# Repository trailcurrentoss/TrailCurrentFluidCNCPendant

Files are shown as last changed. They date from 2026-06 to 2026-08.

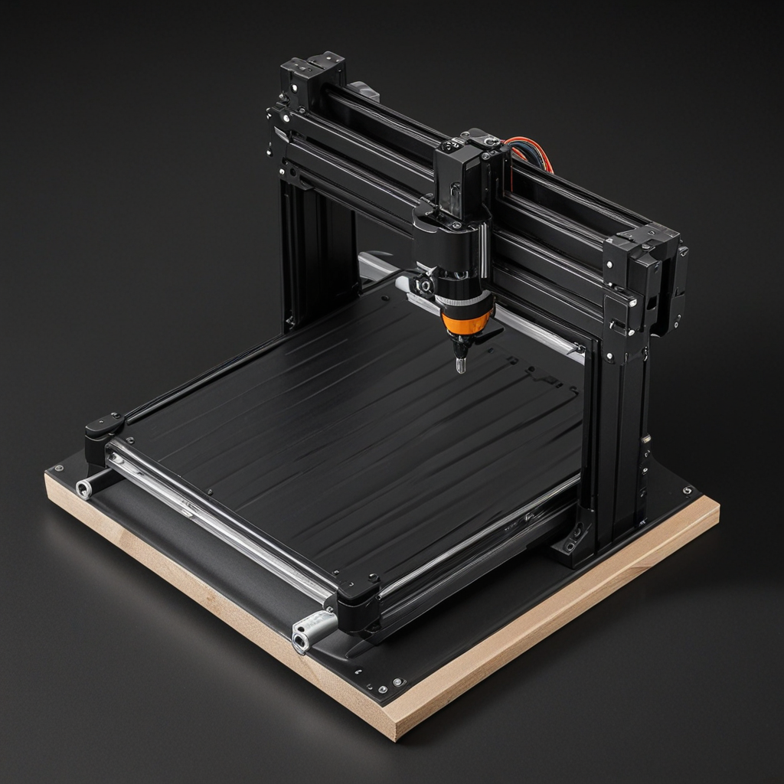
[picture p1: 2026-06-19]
assets/images/cnc_machine.png

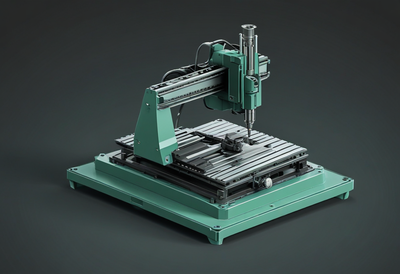
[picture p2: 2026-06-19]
assets/images/cnc_machine_ui.png

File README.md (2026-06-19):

# TrailCurrent FluidCNC Pendant

> # ⚠️ DEMONSTRATION CODE ONLY — DO NOT USE ON A REAL CNC MACHINE ⚠️
>
> **This project is published for educational and demonstration purposes only.**
> It is **not** a production CNC pendant. It has **not** been validated for
> safety, reliability, or fitness for any purpose. **DO NOT** use it to control
> a real CNC machine — milling, lathe, laser, plasma, router, or otherwise.
>
> CNC machines are dangerous. They can injure you, others, or damage equipment
> and material if commands are sent incorrectly, are ignored, or arrive out of
> order. This pendant offers **no safety guarantees**: commands can be dropped,
> rejected, delayed, or executed in unexpected sequences. The on-screen
> "E-STOP" button is **not** a substitute for a hardware emergency stop.
>
> If you build, flash, or modify this code, you do so **entirely at your own
> risk**. The authors and contributors accept **no liability** for any damage,
> injury, loss, or other consequences arising from its use or misuse.
>
> For real CNC control, use FluidNC's official tools and a properly engineered
> physical e-stop circuit wired directly to your controller.

---

A touch-screen control panel for [FluidNC](https://github.com/bdring/FluidNC)
CNC controllers. Mount it on the side of your CNC machine and use it to
home the spindle, jog the axes, start a job, set work coordinates, run macros,
and watch what the machine is doing — all without reaching for a laptop.

**Hardware:** [Waveshare ESP32-P4 WiFi6 Touch LCD 7B](https://www.waveshare.com/wiki/ESP32-P4-WIFI6-Touch-LCD-7B) — 7-inch 1024×600 capacitive touch panel with an ESP32-P4 main chip and an ESP32-C6 WiFi co-processor.
**Firmware:** ESP-IDF 5.5.x · LVGL 8.4 · UI authored in [EEZ Studio](https://www.envox.eu/studio/).

---

## Quick start

1. Flash the firmware — see [docs/06-building-and-flashing.md](docs/06-building-and-flashing.md).
2. On first boot the pendant scans for WiFi networks — pick yours, enter the password.
3. Open Settings → Machine → "Configure FluidNC Connection" — type your
   controller's hostname or IP, pick **WebSocket** for wireless or **UART** for wired.
4. Tap **Connect** and the pendant lands on the Dashboard with live machine readouts.

## Documentation

Full documentation lives in [docs/](docs/). Start with [docs/README.md](docs/README.md) for a guided tour.

| If you want to… | Read |
|---|---|
| Understand what the pendant does and who it's for | [01-overview.md](docs/01-overview.md) |
| Get the pendant onto WiFi and talking to your CNC | [02-getting-started.md](docs/02-getting-started.md) |
| Know what every screen does | [03-screen-tour.md](docs/03-screen-tour.md) |
| Understand how it talks to FluidNC under the hood | [04-how-it-talks-to-fluidnc.md](docs/04-how-it-talks-to-fluidnc.md) |
| Read the code — what lives where | [05-architecture.md](docs/05-architecture.md) |
| Build and flash the firmware | [06-building-and-flashing.md](docs/06-building-and-flashing.md) |
| Change colors, add screens, or modify behavior | [07-customizing.md](docs/07-customizing.md) |
| Fix something that's not working | [08-troubleshooting.md](docs/08-troubleshooting.md) |

## Project layout

| Path | Purpose |
|---|---|
| [main/](main/) | Application code — state machine, action handlers, variable bridge |
| [main/ui/](main/ui/) | UI generated by EEZ Studio — **never edit by hand** |
| [GUI/](GUI/) | EEZ Studio project file (`.eez-project`) — source of truth for the UI |
| [components/fluidnc/](components/fluidnc/) | FluidNC protocol — WebSocket / UART transports, grbl parser, dispatcher |
| [components/wifi_setup/](components/wifi_setup/) | WiFi scan + connect via the ESP32-C6 co-processor |
| [components/pendant_config/](components/pendant_config/) | Persistent settings stored in NVS (flash) |
| [assets/](assets/) | Source images, fonts, icons referenced by the EEZ Studio project |
| `sdkconfig.defaults` | Pinned project config — edit here, never `sdkconfig` |

## Status

- ✅ All UI screens render and respond to touch
- ✅ Real FluidNC protocol backend (WebSocket + UART), grbl status parser
- ✅ WiFi setup and auto-reconnect via ESP-Hosted to the ESP32-C6
- ✅ Persistent settings (WiFi creds, host, port, units, brightness, theme)
- ✅ Mock backend selectable via `idf.py menuconfig` for bench testing
- 🟡 Probe cycles 1–3 (corner / center / tool length) — only Z touch-off implemented
- 🟡 Pagination for SD listings > 6 files

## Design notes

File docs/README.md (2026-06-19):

# TrailCurrent FluidCNC Pendant — Documentation

Welcome. This folder is the full documentation for the pendant — written so
someone who's never touched the project (and doesn't have a CNC background)
can read it cover to cover and end up knowing what the device does, how to
use it, and how it's built.

## Reading order

If you're new, read in order. If you already know what a CNC is and just
want to set the pendant up, skip to [02 — Getting started](02-getting-started.md).
If you're a developer who wants to modify the code, [05 — Architecture](05-architecture.md)
is the starting point.

| # | Topic | What's in it |
|--:|---|---|
| 01 | [Overview](01-overview.md) | What the pendant is, who it's for, the hardware |
| 02 | [Getting started](02-getting-started.md) | First boot — WiFi setup, connecting to a CNC |
| 03 | [Screen tour](03-screen-tour.md) | Every screen, every button, what it does |
| 04 | [How it talks to FluidNC](04-how-it-talks-to-fluidnc.md) | The protocol in plain English |
| 05 | [Architecture](05-architecture.md) | Code organisation — where things live and why |
| 06 | [Building and flashing](06-building-and-flashing.md) | Compiling and getting firmware on the device |
| 07 | [Customizing](07-customizing.md) | Changing screens, themes, actions |
| 08 | [Troubleshooting](08-troubleshooting.md) | Common problems and how to fix them |

## Glossary

Terms used throughout the docs. Skim once, refer back as needed.

- **CNC** — Computer Numerical Control. A milling machine, lathe, plasma cutter,
  laser, etc. that moves automatically under software control.
- **FluidNC** — open-source CNC controller firmware that runs on an ESP32 board
  connected to the stepper drivers. The pendant talks to it as a remote.
- **g-code** — the text language CNC machines speak. Commands look like
  `G1 X100 Y50 F1500` (move to X=100, Y=50 at 1500 mm/min). The pendant sends
  these to FluidNC behind the scenes when you tap a button.
- **grbl** — an older CNC firmware FluidNC inherits its wire protocol from. The
  status reports and realtime control bytes the pendant uses come from grbl.
- **Jog** — small, manually-commanded movement (used to position the spindle
  before running a job).
- **Home** — automatic move to the machine's reference position, used so the
  controller knows where the spindle physically is.
- **WCS** — Work Coordinate System. Lets you set "this corner of my material
  is zero" without moving the machine. FluidNC supports 6: `G54`–`G59`.
- **DRO** — Digital ReadOut. The big numbers on the screen showing where the
  spindle currently is.
- **LVGL** — the C library that draws everything on the screen.
- **EEZ Studio** — the visual designer used to lay out the pendant's screens.
  Saves to a `.eez-project` JSON file, which the build process turns into C code.
- **ESP-IDF** — Espressif's development framework for the ESP32 family of chips.
  Provides the compiler, flashing tool, and system libraries.
- **NVS** — Non-Volatile Storage. A small flash partition where the pendant
  remembers your WiFi password, controller address, and preferences.

If a term shows up in the docs that isn't here, let us know — we'll add it.

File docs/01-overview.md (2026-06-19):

# 01 — Overview

## What is the pendant?

It's a 7-inch touchscreen that sits next to your CNC machine and acts as
the everyday control surface for it. You touch the screen to jog the
spindle, start a job, set zero positions, adjust feed and spindle speed,
and watch what the machine is doing.

Today most people running [FluidNC](https://github.com/bdring/FluidNC) (the
controller firmware this pendant talks to) reach the controller through a
web browser on a laptop or phone — point it at the controller's IP address
and you get the FluidNC web UI. That works, but it means a laptop on the
shop bench, an open browser tab, and your attention split between the
screen and the machine.

The pendant replaces that web UI with a purpose-built, always-on,
single-purpose touch panel. It mounts on the side of the machine. You walk
up, tap, and it does the thing.

```
┌─────────────────────────────────────────────────────────┐
│  ●  TrailCurrent              ●  IDLE   G54   --:--     │  ← Status bar
├─────────────────────────────────────────────────────────┤
│  ALARM RIBBON (hidden unless the machine alarms)        │
├─────────────────────────────────────────────────────────┤
│                                                         │
│            Whatever the active screen is                │
│            (Dashboard, Jog, Files, …)                   │
│                                                         │
├─────────────────────────────────────────────────────────┤
│  ▥ Dash · ✥ Jog · ▶ Run · 🗎 Files · 𝍝 Spindle · …      │  ← Bottom dock
└─────────────────────────────────────────────────────────┘
```

## Who is it for?

- **Hobbyists** running a small CNC mill, router, plasma cutter, or laser
  with a FluidNC controller, who want a tidy permanent control surface
  instead of a laptop on the bench.
- **Small shops** that want a consistent, fast UI for operators who
  shouldn't need to learn the browser-based FluidNC web UI.
- **Makers building their own CNC** who already have FluidNC on the
  controller side and want a matching front panel.

You **do not** need this pendant if FluidNC's built-in web UI on your phone
or laptop is meeting your needs — this is a hardware-and-software project
that involves buying a specific touchscreen and flashing firmware to it.

## What runs on it?

| Component | What it is |
|---|---|
| **Hardware** | Waveshare ESP32-P4 WiFi6 Touch LCD 7B board — a 7-inch 1024×600 capacitive touch panel with an ESP32-P4 main chip (no WiFi of its own) and a small ESP32-C6 co-processor that handles WiFi. |
| **Firmware framework** | [ESP-IDF 5.5](https://docs.espressif.com/projects/esp-idf/) — Espressif's official development framework. Provides the compiler, FreeRTOS, drivers, and flash tools. |
| **Graphics library** | [LVGL 8.4](https://lvgl.io/) — a lightweight C library that draws all the widgets (buttons, sliders, labels) and handles touch input. |
| **UI design tool** | [EEZ Studio](https://www.envox.eu/studio/) — a free visual editor for LVGL screens. The pendant's layout is designed in EEZ Studio and saved as a JSON file under [GUI/](../GUI/). |
| **CNC protocol** | The pendant speaks the same wire protocol FluidNC inherited from [grbl](https://github.com/grbl/grbl) — short g-code lines (`G0 X10`) and single "realtime" control bytes (`?` for status, `!` for hold, etc.). |

## What does it *not* do?

- It does **not** generate g-code. You create g-code somewhere else (CAM
  software like Fusion 360, Carbide Create, Kiri:Moto, etc.) and put the
  files onto FluidNC's SD card or local filesystem. The pendant browses
  and runs those files; it doesn't author them.
- It does **not** control stepper motors or relays directly. The CNC
  controller (an ESP32 board running FluidNC firmware) does all the
  motion. The pendant just talks to it.
- It does **not** include an emergency stop hardware button. The
  on-screen E-STOP sends a soft-reset command to FluidNC, which stops
  motion — but for real safety you should still have a physical
  emergency stop wired directly to the controller's input.
- It does **not** record video, host a camera, or stream the workshop
  anywhere. It's a control panel, not a monitor.

## How is it organised?

The pendant has **10 screens**, grouped in two phases:

**Setup screens** (shown only when there's something to set up):

- **WifiSetup** — scan and join a WiFi network
- **FluidConnect** — tell the pendant your controller's address and connect

**Operating screens** (the eight tabs in the bottom dock):

- **Dashboard** — the home screen; big position display, job progress, override sliders
- **Jog** — manually move each axis, zero coordinates, switch units
- **Run** — start/stop the current job, see g-code preview, monitor progress
- **Files** — browse the controller's SD card, pick a file to load
- **Spindle** — RPM dial, target speed, coolant on/off
- **Probe** — touch-off cycles for finding work zero or tool length
- **Macros** — eight one-tap shortcuts for things like "park", "tool change", "warm up spindle"
- **Settings** — preferences (units, brightness, theme), system info, WiFi management

[Chapter 03 — Screen tour](03-screen-tour.md) walks through each screen in detail.

## Where to next?

- If you have the hardware and want to use it: **[02 — Getting started](02-getting-started.md)**.
- If you just want to know what each screen does: **[03 — Screen tour](03-screen-tour.md)**.
- If you're a developer wanting to read the code: **[05 — Architecture](05-architecture.md)**.

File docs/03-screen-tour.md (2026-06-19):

# 03 — Screen tour

This chapter walks through every screen and every button. If you're trying
to figure out "what does this do?" while looking at the pendant, this is
the chapter to keep open.

## Things common to every screen

### Top status bar

Always visible at the top of every operating screen.

```
●  TrailCurrent  ●  IDLE   G54   13:42   📶   ‖ HOLD  ⏹ E-STOP   X 12.345  Y 67.890  Z  -1.230
```

- **● TrailCurrent** — brand mark on the left.
- **● Status pill** — a coloured chip showing the controller's state:
  - **IDLE** (neutral) — the controller is on but not moving.
  - **RUN** (green) — running a job or jogging.
  - **JOG** (green) — actively jogging in response to your taps.
  - **HOLD** (orange) — feed hold is engaged (paused mid-motion).
  - **HOMING** (orange) — running a homing cycle.
  - **ALARM** (red) — something tripped; the controller will refuse to move
    until you reset the alarm.
  - **OFFLINE** (red) — the pendant can't reach the controller.
- **G54** — the active work coordinate system.
- **13:42** — the on-board clock (not yet wired to network time; static for now).
- **📶 WiFi icon** — shown when the pendant is connected to WiFi.
- **‖ HOLD button** — same as the realtime feed hold: tap to pause motion.
  When already held, the label changes to **▶ RESUME**.
- **⏹ E-STOP button** — soft reset; stops motion and puts the controller in
  alarm state. For real emergencies you should still have a hardware
  e-stop wired to the controller.
- **X / Y / Z mini-DRO** — current position, condensed. Same as the big
  DRO on Dashboard / Jog but always visible no matter what screen you're on.

### Alarm ribbon

Appears as a red band below the status bar **only when the machine is in
alarm**. Shows the alarm code and a description; tap **RESET** on the
right side to clear it (sends `$X` to FluidNC).

### Bottom dock

Always visible at the bottom. Eight icon-and-label buttons that switch
between operating screens. The active one is highlighted.

```
▥ Dash   ✥ Jog   ▶ Run   🗎 Files   𝍝 Spindle   ✚ Probe   ⚡ Macros   ⚙ Settings
```

---

## Dashboard (▥ Dash)

The home screen. Everything you need to see at a glance during a job.

```
┌──────────────── Top status bar ────────────────┐
├────────────────────────────────────────────────┤
│  POSITION                          mm          │
│  X  [+12.345]   ▣Zero                          │
│  Y  [+67.890]   ▣Zero                          │
│  Z  [ -1.230]   ▣Zero                          │
├────────────────────────────────────────────────┤
│  FEED 100%   ─◖████████◗────  − +              │
│  RAPID 100%  ─◖████████◗────  − +              │
│  SPINDLE 100%─◖████████◗────  − +              │
├────────────────────────────────────────────────┤
│  JOB · bracket_v3.nc · 23%                     │
│  ████████░░░░░░░░░░░░░░░ Line 142 / 612        │
│  Elapsed 02:45    ETA 09:12                    │
├────────────────────────────────────────────────┤
│  𝍝 Spindle 12000 rpm   ⛆ Flood   ☷ Mist   ⌂ Home│
└─────────────────── Bottom dock ────────────────┘
```

- **POSITION card** — work-coordinate position, big. Tapping the **Zero**
  button next to an axis zeros that axis in the active WCS (sends
  `G10 L20 P0 X0`). The unit (mm or in) sits at the top right and reflects
  whatever you've picked in Settings.
- **Override card (Feed / Rapid / Spindle)** — three rows showing each
  override percentage. Tap **−** to drop by 10, **+** to bump by 10, and
  tap the percentage value itself to reset to 100. The bars fill to
  visualise the current value. *Note:* Rapid only has three legal grbl
  values (25 %, 50 %, 100 %) so taps cycle between those.
- **JOB card** — only meaningful during a run. Shows file name, percent,
  current line / total lines, elapsed time, ETA. When no job is running
  it shows placeholders.
- **Tile row** — four quick-access tiles:
  - **𝍝 Spindle** — tap to start/stop the spindle at the current target RPM.
  - **⛆ Flood** — toggle coolant flood (`M8` / `M9`).
  - **☷ Mist** — toggle coolant mist (`M7` / `M9`).
  - **⌂ Home** — run `$H` (homing cycle). The pendant will refuse if the
    controller is in alarm or already running.

## Jog (✥ Jog)

For manually moving the spindle around. Two DROs (work + machine
coordinates), a WCS picker, units, step-size buttons, and the directional pad.

- **Work / Machine DRO** — two columns, X/Y/Z each. Work is in the active
  WCS; machine is from the homed reference. Both update live.
- **WCS chips (G54–G59)** — tap any to switch active WCS (sends the
  matching g-code). The currently active one stays highlighted.
- **Units chips (mm / in)** — switch the controller's units (`G21` / `G20`)
  and the on-screen formatting. Saved to flash so it survives reboot.
- **Step size buttons (0.01 / 0.1 / 1.0 / 10)** — picks how far each tap
  of a direction button moves the spindle. Distance is in the current units.
- **Directional pad** — X+/−, Y+/−, Z+/−, with a Home button in the centre.
  Each tap fires a `$J=…` jog command at the current step size and the
  feed rate from Settings → Motion → Default Jog Feed.
- **Zero row (X 0 · Y 0 · Z 0 · All 0)** — instant zero buttons for each
  axis or all three at once.

## Run (▶ Run)

The job runner. Open this screen when you're about to start cutting.

- **Header card** — current file name, percent complete, progress bar,
  elapsed time, time remaining, current line.
- **G-code preview** — scrolling window of 20 lines of the program around
  the line currently executing. Line numbers on the left, g-code text on
  the right. (Static placeholder text today; live preview to come.)
- **Status card** — quick read of spindle RPM, feed rate, coolant state.
- **Start / Hold / Stop buttons**:
  - **▶ Start** — begins running the file currently loaded
    (`$LocalFS/Run=/spiffs/<name>` to FluidNC).
  - **‖ Hold** — feed hold (`!` realtime byte).
  - **⏹ Stop** — soft-reset then `$X` — stops motion and clears the alarm
    state so you can immediately run again or jog.

## Files (🗎 Files)

Browser for the g-code files stored on the FluidNC controller's local
filesystem (or SD card, depending on your FluidNC config).

- **Left side — file list** — up to 6 rows showing file name, size, date.
  Tap a row to select it (highlights green). The file count is shown above.
- **Refresh button** — re-queries the controller's file listing
  (`$LocalFS/List`). Useful after you've uploaded a new file via FluidNC's
  web UI.
- **Right side — Selected card** — shows the currently selected file's
  name and metadata (size, line count, runtime estimate).
- **Load & Run button** — equivalent to tapping the file then going to Run
  and tapping Start; one-tap shortcut.
- **Staging card** — placeholder for upload progress when streaming files
  from the pendant (not yet implemented; SD-on-controller is the current path).

> The pendant doesn't store g-code files itself — it always reads them
> from the controller. To get a new file onto the controller, use FluidNC's
> web UI (browse to its IP address in any browser) and upload there, then
> tap Refresh on the pendant.

## Spindle (𝍝 Spindle)

Dedicated spindle control screen, more detailed than the Dashboard tile.

- **Left card — RPM dial** — a big arc showing current RPM vs the target.
  Below it a Start/Stop button (label changes based on state).
- **Target card** — current target RPM with **−** / **+** buttons that
  step by 500 RPM. The displayed target is the value sent to FluidNC the
  next time the spindle is started (or, if already spinning, sent
  immediately as a new `M3 S…` line).
- **Load card** — spindle load (% of max). FluidNC reports this if the
  spindle driver supports load reporting; otherwise it stays at 0.
- **Coolant card** — Flood and Mist toggles. Same actions as the
  Dashboard tile row.

## Probe (✚ Probe)

Touch-off cycles for finding the surface of your material (so the
controller knows where Z=0 is) and similar reference operations.

- **Probe cycle picker (left)** — four cycle types:
  - **Z touch-off** — basic Z probe down + back off + set Z. *Implemented.*
  - **Corner** — find an outside corner of the stock. *Not yet implemented.*
  - **Center** — find the centre of a circular pocket / boss. *Not yet implemented.*
  - **Tool length** — measure tool length offset. *Not yet implemented.*
- **Parameters (right)** — three values:
  - **Plate thickness** — thickness of your probing plate in mm.
  - **Feed** — probe approach speed in mm/min.
  - **Travel** — maximum distance the probe will try before giving up.
- **Probe Z indicator** — last measured Z value. Shows "—" before a probe runs.
- **Start Probe button** — sends the probe sequence based on the selected cycle.

## Macros (⚡ Macros)

Eight tiles, each running a preset multi-line g-code snippet. Defaults
shipped:

| Tile | Macro |
|---|---|
| Go To Front | `G53 G90 G0 Z0` then `G53 G0 X0 Y0` |
| Tool Change | `M6` |
| Probe Z | `G38.2 Z-25 F100` |
| Spindle Warm | `M3 S8000` · `G4 P60` · `M5` |
| Set G54 Zero | `G10 L20 P1 X0 Y0 Z0` |
| Spindle Warmup | (duplicate of Spindle Warm) |
| Park Rear Right | `G53 G0 X-10 Y-10` |
| Unlock | `$X` |

To change what a macro does, edit the `k_macros[]` array in
[main/actions.c](../main/actions.c) and rebuild.

## Settings (⚙ Settings)

Tabbed settings page with five sub-tabs along the left.

### Settings → Machine

- **Units** — mm / inch. Sends `G21` / `G20` to the controller and saves
  the preference to flash.
- **Home on boot** — switch. If on, the pendant tells the controller to
  home immediately on connect. *Stored as a preference; behaviour wiring
  is a follow-up.*
- **Configure FluidNC Connection** — opens the FluidConnect screen so you
  can change the controller host / port / transport without re-doing WiFi.

### Settings → Connection

- **SSID** — the WiFi network the pendant is currently connected to.
- **State** — `Connected · 192.168.x.y` / `Disconnected` / `Failed`.
- **Change Network** — kicks the pendant back to the WiFi setup screen
  so you can pick a different network.
- **Forget** — drops the saved credentials and disconnects. Next boot
  will show the WiFi setup screen.

### Settings → Motion

- **Soft limits** — switch (preference only; FluidNC's `$20=1` is set in
  its own YAML).
- **Hard limits** — switch (preference only).
- **Default jog feed** — slider, 60–6000 mm/min. The Jog page uses this
  whenever you tap a directional button.

### Settings → System

Read-only info:

- **Firmware** — what FluidNC version the controller reported (parsed
  from the `[VER:…]` line FluidNC sends on `$I`).
- **Controller** — the chip identifier the controller reported.
- **UI** — `LVGL 8.4 · 1024x600`.
- **Network** — same string as the Connection tab's State field.

### Settings → Display

- **Brightness** — slider 0–255 with live preview. Saved to flash.
- **Screen timeout** — minutes until the screen blanks for inactivity
  (0 = never). Tapping the dark screen wakes it.
- **Theme** — Light / Dark. The Dark theme is the production look;
  Light is currently a near-mirror (placeholder for a real light palette).

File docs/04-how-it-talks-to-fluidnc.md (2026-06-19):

# 04 — How it talks to FluidNC

This chapter explains the conversation between the pendant and the
FluidNC controller. You don't need to read it to use the pendant — it's
here for the curious, and for anyone debugging a connection that's not
behaving.

## The big picture

The FluidNC controller speaks an old, simple, text-based protocol it
inherited from a project called grbl. Lines of text go in either
direction over the link (WiFi or wired serial). The pendant is just a
client that:

1. **Polls** the controller four times a second for its current state
   ("where's the spindle? what's running? any alarms?"), and
2. **Sends commands** when you tap buttons ("move +1 mm in X", "start
   spinning at 12000 rpm", "stop everything").

```
   ┌─────────────────┐                   ┌─────────────────┐
   │  PENDANT        │                   │  FluidNC        │
   │  (ESP32-P4)     │ ── "?" ─────────▶ │  controller     │
   │                 │                   │  (ESP32 board   │
   │                 │ ◀── "<Idle|...>" ─│  + stepper      │
   │                 │                   │   drivers)      │
   │                 │ ── "G0 X10" ────▶ │                 │
   │                 │ ◀── "ok" ─────────│                 │
   └─────────────────┘                   └─────────────────┘
```

## What goes over the wire

### Status reports (the most common message)

Four times a second the pendant sends a single byte: `?` (question mark).
FluidNC responds with one line in angle brackets, packed with comma-
separated key-value fields:

```
<Run|MPos:12.345,67.890,-1.230|FS:1500,12000|Ov:100,100,100|Pn:|A:SF>
```

Decoded:

- `Run` — current state (Idle / Run / Hold / Jog / Home / Alarm / Door / Check / Sleep)
- `MPos:12.345,67.890,-1.230` — machine position (X, Y, Z), in mm by default
- `FS:1500,12000` — current feed rate (mm/min) and spindle speed (rpm)
- `Ov:100,100,100` — feed / rapid / spindle override percentages
- `Pn:` — triggered pin flags (probe, limits) — empty here means none
- `A:SF` — accessory state: `S` = spindle clockwise, `F` = flood on

The pendant parses this in [src/proto.c](../components/fluidnc/src/proto.c)
and updates every widget that displays one of these values — DRO numbers,
status pill text and colour, override bars, spindle dial, coolant tile
states.

### Realtime control bytes (single byte, no newline)

Some controls bypass the line-by-line command queue because they need to
take effect immediately:

| Byte | Hex  | Meaning |
|---|---|---|
| `?` | `0x3F` | Status report request |
| `!` | `0x21` | Feed hold (pause motion mid-move) |
| `~` | `0x7E` | Cycle start / resume |
| `\x18` | `0x18` | Soft reset (used as E-STOP) |
| `\x85` | `0x85` | Jog cancel |
| `\x90`–`\x9D` | | Feed / rapid / spindle override step commands |
| `\xA0` | `0xA0` | Toggle flood coolant |
| `\xA1` | `0xA1` | Toggle mist coolant |

The pendant uses these for the E-STOP button, the HOLD / RESUME button,
and the override − / + buttons. They go out instantly without queueing.

### G-code lines (everything else)

Anything that takes a `\n` to terminate is g-code. The pendant
constructs and sends:

| Pendant action | What the pendant sends |
|---|---|
| Tap Jog X+ at 1 mm, 1200 mm/min | `$J=G91 G21 X1.0000 F1200.0\n` |
| Zero X in current WCS | `G10 L20 P0 X0\n` |
| Switch to G55 | `G55\n` |
| Switch to inch | `G20\n` |
| Home all | `$H\n` |
| Start spindle at 12000 | `M3 S12000\n` |
| Stop spindle | `M5\n` |
| Flood on / off | `M8\n` / `M9\n` |
| Reset alarm | `$X\n` |
| Start a job | `$LocalFS/Run=/spiffs/bracket_v3.nc\n` |
| Get file listing | `$LocalFS/List\n` |
| Z probe | `G38.2 Z-25 F100\n` then `G10 L20 P0 Z19.00\n` then `G0 Z24.00\n` |

The controller responds to each line with `ok` (accepted) or `error:N`
(rejected, where N is the grbl error code). The pendant doesn't surface
every error today — that's a future enhancement.

## Transports

The pendant supports three ways to physically reach the controller. You
pick one on the FluidConnect screen.

### WebSocket (wireless — recommended)

FluidNC exposes the grbl protocol over a WebSocket on
`ws://<controller-ip>:81/` (FluidNC 3.x) or `ws://<controller-ip>:80/`
(FluidNC 4.x). The pendant connects via the
[`esp_websocket_client`](https://components.espressif.com/components/espressif/esp_websocket_client)
library and treats each WebSocket text frame as one or more newline-
separated grbl lines.

Source: [src/transport_ws.c](../components/fluidnc/src/transport_ws.c).

### UART (wired)

If WiFi isn't reliable in your shop, or you just prefer wires, the
pendant can talk grbl over a UART pair instead. Wiring:

- Pendant GPIO 5 (TX) → Controller RX
- Pendant GPIO 4 (RX) → Controller TX
- Pendant GND → Controller GND
- 115200 8N1, no flow control

Match this baud rate in your FluidNC YAML config (usually under
`uart1:` or similar). Source:
[src/transport_uart.c](../components/fluidnc/src/transport_uart.c).

### Telnet (stub)

The pendant config knows about Telnet because FluidNC exposes one, but
the transport isn't implemented yet. Picking it returns a "not supported"
error. WebSocket is functionally equivalent for almost every use case.

## Inside the pendant — the dispatcher

When the pendant talks to FluidNC, three things happen on three different
FreeRTOS tasks:

1. **Status-poll task** — sends a `?` byte every 250 ms when the link is up.
2. **RX-parse task** — reads incoming bytes one chunk at a time, splits
   them at newlines, classifies each line (`<Status>`, `ok`, `error:N`,
   `[FILE:…]`, etc.), and updates the cached status struct.
3. **The widget refresh** — after every parsed status report, a callback
   fires that pushes the new values into the UI variables, which in
   turn update every relevant LVGL widget across all 8 screens.

The dispatcher (the brains tying these together) is in
[src/fluidnc.c](../components/fluidnc/src/fluidnc.c). The public API
(`fluidnc_jog`, `fluidnc_spindle_on`, etc.) is in
[include/fluidnc.h](../components/fluidnc/include/fluidnc.h).

## When things go wrong

### Connection drops mid-use

If the WebSocket disconnects, the pendant detects it and tries to
reconnect automatically. The status pill flips to **OFFLINE** while
disconnected and back to **IDLE** (or whatever state) when the link
recovers. UART links don't auto-detect drop the same way; you have to
pull power and reconnect.

### Controller alarms

When FluidNC enters alarm state, its next status report includes an
`Alarm` state token and the pendant:

1. Flips the status pill to red.
2. Shows the red **Alarm ribbon** across the top of every screen.
3. Refuses to send motion commands (e.g. jog) until alarm is cleared.

Tap **Reset** on the alarm ribbon (or the alarm-state pill) to send
`$X` and clear it.

### Commands that don't take effect

If you tap a button and nothing happens, possibilities are:

- The controller is in alarm (motion blocked until cleared).
- The controller is running a job (some commands queue, some are ignored).
- The link is down (status pill shows OFFLINE).
- The command was sent but FluidNC rejected it with `error:N` — these
  are logged on the pendant's serial console (USB-C) but not currently
  shown on screen.

For more on debugging, see [08 — Troubleshooting](08-troubleshooting.md).

## Mock backend (for bench testing without a real controller)

If you want to develop or demo the pendant without hooking it up to a
real CNC, the project ships a mock backend that simulates motion,
spindle ramp, file listings, and job progress. Enable it via:

```bash
idf.py menuconfig
# → TrailCurrent FluidNC → Use mock backend → Y
idf.py build flash
```

The mock lives in
[src/fluidnc_mock.c](../components/fluidnc/src/fluidnc_mock.c). It's
useful when:

- You want to test UI changes without standing next to a CNC.
- You want to record demo video of the pendant.
- The real controller isn't built/wired yet.

To go back to the real backend, set the option to N and rebuild.

## Useful FluidNC documentation

- [FluidNC wiki](https://github.com/bdring/FluidNC/wiki) — official docs
- [grbl realtime commands](https://github.com/gnea/grbl/wiki/Grbl-v1.1-Commands#real-time-commands) — full byte list
- [grbl status report format](https://github.com/gnea/grbl/blob/master/doc/markdown/interface.md#status-reporting) — field reference

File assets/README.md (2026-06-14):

# Assets

Source artwork that feeds the EEZ Studio project in [../GUI/](../GUI/). EEZ Studio imports from here; **nothing in this folder is consumed at firmware build time** — it is design-time material only.

## Layout

```
assets/
├── fonts/
│   └── fontawesome/         # OTF (Solid, Regular, Brands) — for LVGL font subsetting
├── icons/
│   └── fontawesome/         # Font Awesome 7.2.0 Free icon raster + vector sets
│       ├── svg/{solid,regular,brands}/        # 2860 vector source SVGs
│       ├── png16/{solid,regular,brands}/      # 2860 PNGs rasterized at 16x16 px
│       ├── png32/{solid,regular,brands}/      # 2860 PNGs rasterized at 32x32 px
│       └── LICENSE.txt
├── images/                  # Project bitmap art (screen backgrounds, logos, etc.)
└── source/                  # Editable masters (SVG, AI, PSD, FreeCAD exports, …)
```

## Font Awesome

- Version: **7.2.0 Free** (CC BY 4.0 for icons, SIL OFL 1.1 for fonts, MIT for code — see `LICENSE.txt`).
- Family counts: solid (2000), regular (273), brands (587). Total: **2860 icons**.
- PNGs are black-on-transparent ARGB, centered, uniformly scaled to fit the canvas.
- Use the **SVG** when EEZ Studio is the consumer (vector → any size, recolorable).
- Use the **PNG** when you need a guaranteed pixel-aligned raster at the chosen size.
- Use the **OTF** when subsetting an LVGL icon font (typical for buttons that mix icon+text).

## Adding new assets

1. Drop the master file into `assets/source/`.
2. Export the production-format file (PNG / SVG) into `assets/images/` or `assets/icons/`.
3. Import into EEZ Studio from there.

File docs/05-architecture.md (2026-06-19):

# 05 — Architecture

A developer-oriented map of the codebase: what files exist, what
responsibilities each one has, and how they wire up.

If you've never read an ESP-IDF project before, the [README's project
layout table](../README.md#project-layout) and this chapter together
should be enough to find your way around.

## The 30-second summary

```
                       ┌──────────────────────────────────┐
                       │  EEZ Studio (.eez-project JSON)  │
                       │  ─ designed in the GUI app       │
                       │  ─ defines every screen, style,  │
                       │    action declaration, font      │
                       └──────────────┬───────────────────┘
                                      │  Build (Ctrl+B in EEZ Studio)
                                      ▼
                       ┌──────────────────────────────────┐
                       │  main/ui/*.c|*.h  (GENERATED)    │
                       │  ─ screens.c: every widget       │
                       │  ─ actions.h: action prototypes  │
                       │  ─ vars.h:    get/set prototypes │
                       └──────────────┬───────────────────┘
                                      │  linked with
                                      ▼
                       ┌──────────────────────────────────┐
                       │  main/  (HAND-WRITTEN C)         │
                       │  ─ main.c:      boot + LVGL init │
                       │  ─ app_state.c: state machine    │
                       │  ─ actions.c:   button handlers  │
                       │  ─ vars.c:      widget updaters  │
                       └──────────────┬───────────────────┘
                                      │  uses
                                      ▼
                       ┌──────────────────────────────────┐
                       │  components/  (LIBRARIES)        │
                       │  ─ fluidnc/  CNC protocol        │
                       │  ─ wifi_setup/  WiFi scan+join   │
                       │  ─ pendant_config/  NVS storage  │
                       └──────────────────────────────────┘
```

## Two halves: appearance vs state

The pendant's code follows one rule above all others:

> **EEZ Studio owns appearance. C owns state.**

- Colors, fonts, layouts, padding, borders, icons — all in the EEZ Studio
  `.eez-project` file. Edit them in EEZ Studio's GUI; never set them from C.
- Which widget is highlighted, which screen is showing, what text the
  DRO labels display, whether the alarm ribbon is visible — all in C.
  Code calls `lv_label_set_text(…)`, `lv_obj_add_state(…)`, etc.

If you want to change what something looks like, open EEZ Studio. If you
want to change what something does, open a `.c` file.

## File by file

### Root

- **[README.md](../README.md)** — Top-level intro, project layout, status.
- **[CLAUDE.md](../CLAUDE.md)** — Agent instructions (workflow rules,
  source-of-truth, build pattern). Read if you're contributing.
- **[sdkconfig.defaults](../sdkconfig.defaults)** — ESP-IDF config. Always
  edit this file; never `sdkconfig` (which is regenerated on every build).
- **[partitions.csv](../partitions.csv)** — Flash partition layout (32 MB
  flash: bootloader, partition table, 26 MB app, 5 MB SPIFFS for assets).
- **[CMakeLists.txt](../CMakeLists.txt)** — Top-level project file ESP-IDF
  expects.

### `main/` — application code

This is where the project-specific firmware lives. Everything else is a
library.

- **[main/main.c](../main/main.c)** — Boots NVS, the display via the
  Waveshare BSP, LVGL, then calls `ui_init()` (which builds every screen)
  and hands off to the state machine. Also owns the inactivity-blanking
  task that dims the screen after the configured timeout.

- **[main/app_state.h](../main/app_state.h)** — defines the top-level
  state machine: `BOOT → WIFI_SETUP → WIFI_CONNECTING → FLUID_CONNECT →
  FLUID_CONNECTING → PENDANT`. The state transitions decide which screen
  is showing.

- **[main/app_state.c](../main/app_state.c)** — implementation of the
  state machine. The `on_fluid_status` callback is the heart of the
  app — every status report from the controller flows through here and
  is fanned out into the UI variables.

- **[main/actions.c](../main/actions.c)** — one function per UI action.
  When you tap a button, EEZ Studio's generated `screens.c` registers a
  `LV_EVENT_CLICKED` handler that calls one of these. Conventions:
  - `evt_user_data(e)` returns the `userData` byte set in EEZ Studio,
    used to distinguish variants of one action (e.g. `ChangeScreen` with
    userData 0–7 for the 8 tabs).
  - `selector_swap(target, group, n)` is the helper used for any
    mutually-exclusive selector group (WCS chips, units, jog step,
    transport cards, etc.).

- **[main/vars.c](../main/vars.c)** — the **bridge** between the
  controller's status and the LVGL widgets. EEZ Studio's generated
  `vars.h` declares `set_var_<name>()` / `get_var_<name>()` for every
  global variable in the project; `vars.c` implements each one. Two flavours:
  - **Cache-only** setters (`VAR_STRING`, `VAR_INT`, `VAR_BOOL` macros) — just
    store the value, nothing else.
  - **Cache + widget-update** setters — hand-written to also push the new
    value into one or more widgets. Most of vars.c is this kind.

  Setters that fan out to many widgets (status bar lives on all 8 screens,
  so the WCS label / mini DRO / status pill is duplicated 8 times) loop
  over a static array of widget pointers.

- **[main/ui/](../main/ui/)** — **generated** by EEZ Studio's Build
  (Ctrl+B). Don't hand-edit; changes get clobbered on next export.
  - `screens.c` / `screens.h` — every widget object and the
    `create_screen_<name>()` constructors.
  - `actions.h` — `extern void action_<Name>(lv_event_t *e);` prototypes.
  - `vars.h` — `extern <type> get_var_<name>()` / `set_var_<name>()`
    prototypes for every global.
  - `styles.c` / `styles.h` — every named style.
  - `images.c` / `images.h` / `ui_image_*.c` — bitmap data.
  - `fonts.h` / `ui_font_*.c` — converted glyph data.
  - `ui.c` / `ui.h` — `ui_init()` that calls every screen's create function.

- **[main/CMakeLists.txt](../main/CMakeLists.txt)** — lists every source
  file in the `main` component, including every `ui/ui_font_*.c` and
  `ui/ui_image_*.c` from EEZ Studio. Add a new bitmap or font here when
  EEZ Studio emits one.

### `components/fluidnc/` — the CNC protocol

The most complex component. Three sub-systems:

- **Dispatcher** ([src/fluidnc.c](../components/fluidnc/src/fluidnc.c)):
  picks a transport at connect time, runs the status-poll task, runs the
  RX-parse task, exposes the high-level command API (`fluidnc_jog`,
  `fluidnc_spindle_on`, etc.).

- **Parsers** ([src/proto.c](../components/fluidnc/src/proto.c)): pure C
  string parsing for the grbl status report, classification of incoming
  lines (`ok`, `error:N`, `[FILE:…]`, etc.), and helpers to extract codes
  and file metadata.

- **Transports** — three implementations of one vtable
  ([src/transport.h](../components/fluidnc/src/transport.h)):
  - **[transport_ws.c](../components/fluidnc/src/transport_ws.c)** —
    WebSocket via `esp_websocket_client`. Used for wireless.
  - **[transport_uart.c](../components/fluidnc/src/transport_uart.c)** —
    UART1 at 115200 8N1 (GPIO 5 TX, 4 RX). Used for wired.
  - **[fluidnc_mock.c](../components/fluidnc/src/fluidnc_mock.c)** —
    bench testing without a real controller. Selected via Kconfig.

The mock and the real backend are mutually exclusive — only one is
compiled in (controlled by `CONFIG_FLUIDNC_USE_MOCK`). Both expose the
same public API in
[include/fluidnc.h](../components/fluidnc/include/fluidnc.h), so the rest
of the project doesn't know or care which one is active.

### `components/wifi_setup/` — joining WiFi networks

- **[include/wifi_setup.h](../components/wifi_setup/include/wifi_setup.h)** —
  public API: `wifi_setup_init`, `wifi_setup_scan_start`, `wifi_setup_connect`,
  `wifi_setup_disconnect`, plus state and result-readout helpers.

- **[src/wifi_setup.c](../components/wifi_setup/src/wifi_setup.c)** —
  brings up the ESP-Hosted bridge to the ESP32-C6 (where the WiFi radio
  lives), starts a STA-mode driver, scans, connects, classifies disconnect
  reasons into the buckets the UI surfaces ("Bad password" / "Network not
  in range" / "Timed out").

### `components/pendant_config/` — persistent storage

- **[include/pendant_config.h](../components/pendant_config/include/pendant_config.h)** —
  the `pendant_config_t` struct (WiFi creds, FluidNC host/port/transport,
  units, limit prefs, home-on-boot) plus init / getter / setters.

- **[src/pendant_config.c](../components/pendant_config/src/pendant_config.c)** —
  reads / writes the NVS namespace `pendant`. Setters update the cache
  AND commit to flash atomically.

### `GUI/` — the EEZ Studio project

- **[GUI/TrailCurrentFluidCNCPendant.eez-project](../GUI/TrailCurrentFluidCNCPendant.eez-project)** —
  the source of truth for the UI. JSON. Edit in EEZ Studio's GUI; build
  with Ctrl+B to regenerate `main/ui/`.

### `assets/` — source images and fonts

The TTF / OTF source files for fonts used in the project, and source PNG
/ SVG / JPG images for any bitmaps. These get embedded into the
generated UI code at EEZ Studio build time — they're not flashed
separately.

## The boot sequence (step by step)

When you power on the pendant:

1. **ESP32-P4 ROM bootloader** runs from on-chip ROM (about 50 ms).
2. **Second-stage bootloader** from the `bootloader` partition (about
   500 ms — sets up flash, PSRAM, clocks).
3. **`app_main()` in [main.c](../main/main.c)** starts:
   1. `nvs_flash_init()` — opens the settings storage.
   2. `esp_event_loop_create_default()` — needed by WiFi later.
   3. `pendant_config_init()` — loads WiFi creds + FluidNC config from NVS.
   4. `bsp_display_start_with_config(...)` — brings up the panel and
      LVGL (this takes about 2 s).
   5. `ui_init()` — builds every screen in memory.
   6. `restore_user_settings_from_nvs()` — restores brightness, timeout,
      jog feed, theme.
   7. `app_state_init()` — initialises WiFi + FluidNC components and
      decides whether to show WifiSetup or auto-reconnect.
4. **Inactivity-blanking task** is spawned to handle screen dimming.
5. **WiFi auto-connect** (if creds are saved) — takes 3–5 s on a typical
   network.
6. **FluidNC auto-connect** (if a controller is configured) — happens in
   the background; the pendant lands on the Dashboard regardless.

The whole thing from power-on to a usable Dashboard is **about 15
seconds** on a typical setup.

## Threading model

The pendant runs FreeRTOS with these tasks:

| Task | Purpose | Stack |
|---|---|---|
| `main_task` | Runs `app_main()` then exits | — |
| `LVGL` task (pinned to core 1) | Owns all LVGL state, draws everything, dispatches touch events | 7 KB |
| `wifi_setup` event handler | Runs on the default event loop task | — |
| `fluidnc_rx` | Parses incoming grbl lines | 4 KB |
| `fluidnc_pol` | Sends `?` every 250 ms | 3 KB |
| `fluidnc_uart_rx` | Reads bytes from UART1 (only in UART mode) | 3 KB |
| `WS-client task` | esp_websocket_client's own RX loop (only in WebSocket mode) | 6 KB |
| `blank` | Watches for inactivity, dims/wakes the screen | 3 KB |

The rule for safe LVGL access is: **always wrap LVGL calls with
`bsp_display_lock()` / `bsp_display_unlock()` if you're not on the LVGL
task**. The variable setters in `vars.c` and the helpers in `app_state.c`
do this for you.

## Where to look when you want to…

| Goal | File(s) |
|---|---|
| Add or change a button's behaviour | [main/actions.c](../main/actions.c) |
| Change what a status field shows | [main/vars.c](../main/vars.c) (setter for that field) |
| Add a new top-level state | [main/app_state.h](../main/app_state.h) + [main/app_state.c](../main/app_state.c) |
| Send a new kind of command to FluidNC | [include/fluidnc.h](../components/fluidnc/include/fluidnc.h) + [src/fluidnc.c](../components/fluidnc/src/fluidnc.c) |
| Add a new field to the grbl status report | [src/proto.c](../components/fluidnc/src/proto.c) + [src/fluidnc.c](../components/fluidnc/src/fluidnc.c) |
| Add a new bitmap | EEZ Studio (add to bitmaps), then `main/CMakeLists.txt` (add `ui/ui_image_<name>.c`) |
| Add a new font | EEZ Studio (add to fonts) + `sdkconfig.defaults` if it's a Montserrat size |
| Change colour palette | EEZ Studio → Themes |
| Change persisted settings shape | [pendant_config.h](../components/pendant_config/include/pendant_config.h) + [pendant_config.c](../components/pendant_config/src/pendant_config.c) |

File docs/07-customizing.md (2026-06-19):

# 07 — Customizing

How to change what the pendant looks like and what it does.

## The two workflows

There are two completely separate workflows depending on what you want
to change:

| To change… | Use |
|---|---|
| Colors, fonts, layout, icons, themes | **EEZ Studio** (visual editor) |
| What happens when a button is tapped, what data updates a label | **A `.c` file** in `main/` |

Both end in `idf.py build flash`, but the editing surface is different.

## Changing what something looks like (EEZ Studio)

1. Install [EEZ Studio](https://www.envox.eu/studio/).
2. Open `GUI/TrailCurrentFluidCNCPendant.eez-project`.
3. Make your edits in the GUI (drag widgets, change colors, edit styles).
4. Save (`Ctrl+S`).
5. **Build** (`Ctrl+B`). This regenerates everything under `main/ui/`.
6. From your terminal: `idf.py build flash` to rebuild and flash.

> ⚠️ **Never edit files inside `main/ui/`.** They're overwritten on every
> Build. Your edits will disappear.

### Common edits

- **Change a colour** — Themes panel (left sidebar). Two themes ship:
  `Default` (light) and `Dark` (production). Click a colour token and
  edit the hex value. The change applies wherever that token is used.
- **Change a font size** — Open the style on the widget, change
  `text_font` to a different value. Use `MONTSERRAT_<n>` (e.g.
  `MONTSERRAT_16`) for sizes that LVGL has built-in; the names
  in lowercase (`mono_13`, `fa_22`) are custom fonts embedded by the
  project.
- **Move a button** — Click it, drag, or edit `left` / `top` / `width` /
  `height` in the properties panel.
- **Change a label's initial text** — Click the label, edit the `text`
  property. (At runtime, code in `vars.c` may overwrite this — see
  *Default vs runtime values* below.)
- **Add a new screen** — Right-click `userPages` → New. Place an
  `LVGLScreenWidget` as the root, then add child widgets inside.

### Default vs runtime values

Many widgets have an *initial* text or value set in EEZ Studio, but get
overwritten the moment data starts flowing. The DRO labels are an
example — they start at `0.000` per the EEZ Studio source, but the moment
the pendant connects to FluidNC, `set_var_work_dro_x()` in
[main/vars.c](../main/vars.c) starts pushing real values into them.

If you want a different default *before* data arrives, change the value
in **both** EEZ Studio (the initial text) and `vars.c` (the cache
default in the `s_v` struct initialiser). Both should agree.

## Changing what a button does (C)

Every interactive button in EEZ Studio has an `eventHandlers` entry
naming an action like `Jog`, `HoldResume`, `JobStart`. EEZ Studio's
Build (Ctrl+B) emits an `extern void action_<Name>(lv_event_t *e);`
prototype into `main/ui/actions.h`. You write the implementation in
[main/actions.c](../main/actions.c).

### Adding a new action

1. **In EEZ Studio**: open the Actions panel, add a new action (e.g.
   `MyNewAction`). Don't add anything inside the action's components
   list — actions are just named declarations when `flowSupport` is
   off (and it is for this project).
2. Wire the action to a button: open the button, click `eventHandlers`,
   add a new entry with `eventName=CLICKED`, `handlerType=action`,
   `action=MyNewAction`, `userData=0`.
3. **Build** (Ctrl+B). EEZ Studio emits the new `action_my_new_action`
   prototype into `main/ui/actions.h`.
4. **In actions.c**, add the implementation:

   ```c
   void action_my_new_action(lv_event_t *e)
   {
       (void)e;
       /* whatever you want this to do */
       fluidnc_send_line("G53 G0 X-100 Y0\n");
   }
   ```

5. `idf.py build flash` and you're done.

### Using userData to disambiguate

Many actions in the project use a single C function for many buttons,
distinguished by `userData`. E.g. `ChangeScreen` has userData 0–7 for
the 8 dock tabs; one handler does the dispatch:

```c
void action_change_screen(lv_event_t *e)
{
    int tab = (int)(intptr_t)lv_event_get_user_data(e);
    app_state_set_pendant_tab(tab);
}
```

Use this pattern when you have many similar buttons (a number pad, a
grid of macros).

### Changing what a macro does

Edit `k_macros[]` in [main/actions.c](../main/actions.c). Eight strings,
each a g-code program (multi-line OK, separate lines with `\n`).

```c
static const char *const k_macros[] = {
    "G53 G90 G0 Z0\nG53 G0 X0 Y0",         /* Go To Front  */
    "M6",                                   /* Tool Change  */
    /* …add yours here… */
};
```

The labels in EEZ Studio (`macros_name_0` etc.) stay where they are —
update them in EEZ Studio if you want the tile to say something
different.

### Changing the jog step sizes or feed default

Edit the `JOG_STEPS_MM` array near the top of
[main/actions.c](../main/actions.c). Four values, in millimetres. The
default feed rate is in NVS under "user_settings/jog_feed" and shown on
the Settings → Motion → Default Jog Feed slider.

## Changing what data updates a widget

When the controller's state changes, the flow is:

1. The dispatcher in [components/fluidnc/src/fluidnc.c](../components/fluidnc/src/fluidnc.c)
   parses the incoming grbl status report and calls the registered
   status callback.
2. `on_fluid_status()` in [main/app_state.c](../main/app_state.c) is the
   callback — it pulls fields out of the status struct and calls the
   appropriate `set_var_<name>()` functions.
3. The setter in [main/vars.c](../main/vars.c) caches the value and
   pushes it into the relevant LVGL widget(s).

If you want a new field to update a widget:

1. **Add the field to the status struct** in
   [include/fluidnc.h](../components/fluidnc/include/fluidnc.h) — e.g.
   `int probe_z_pos;`.
2. **Populate it in proto.c / fluidnc.c** — parse it from the grbl
   status report or wherever it comes from.
3. **Add a global variable in EEZ Studio** (Variables panel) — type
   matches what the widget needs. Build (Ctrl+B) emits the
   `set_var_<name>` prototype.
4. **Implement the setter in vars.c** — at minimum cache the value;
   ideally also push it into the widget (see existing overlays for the
   pattern).
5. **Call the setter from `on_fluid_status`** — `set_var_<name>(st->probe_z_pos);`.

## Changing colours / themes

The project uses **named colour tokens** (e.g. `AccentPrimary`,
`StatusDanger`, `BgCard`) defined once in the `colors` array, then bound
to hex values per theme in the `themes` array. To change a colour:

1. Open the .eez-project in EEZ Studio.
2. Themes panel → click the token you want to change.
3. Edit its hex value for both `Default` and `Dark` themes (or only
   one if the design intentionally differs per theme).
4. Save + Build.

If you want to add a *new* token, add it to `colors`, then add a hex
value at the same index in both themes' `colors` arrays.

> Some tokens are intentionally **theme-invariant** (same colour in both
> themes): `AccentPrimary`, `AxisX/Y/Z`, `StatusSuccess`,
> `StatusWarning`, `StatusDanger`, `ForegroundWhite`, `ForegroundBlack`.
> Don't change those per-theme — they represent semantic colour the
> rest of the design depends on.

## Adding a Font Awesome icon

The project embeds three Font Awesome subsets (`fa_16`, `fa_22`, `fa_28`)
with only the icons currently used. Adding a new icon means:

1. Look up the Unicode codepoint at <https://fontawesome.com/v6/icons>
   (it's in the "Unicode" field, e.g. `f04b` for fa-play).
2. In EEZ Studio, open the font (`fa_16`, `fa_22`, or `fa_28`) in the
   Fonts panel.
3. Add the codepoint to its `lvglRanges` list (comma-separated hex,
   e.g. `0xF04B`).
4. Save the project, close + reopen it so EEZ Studio re-embeds the font.
   (This is one of EEZ Studio's quirks — font re-embedding only fires
   when you edit a font through the GUI.)
5. Set the label's `text` to the UTF-8 encoding of the codepoint. For
   `f04b` this is `""` in EEZ Studio's text field (`"\xEF\x81\x8B"`
   if you're writing it in C).
6. Build (Ctrl+B) + `idf.py build flash`.

## Adding a custom bitmap

1. Drop the source image (PNG / JPG / BMP) into `assets/images/`.
2. In EEZ Studio, Bitmaps panel → Add. Point it at the file.
3. Place an `LVGLImageWidget` on a screen, set `image` to the bitmap's name.
4. Save + Build.
5. **Add the new generated file to the build**: open
   [main/CMakeLists.txt](../main/CMakeLists.txt) and add
   `"ui/ui_image_<bitmap_name>.c"` to the `SRCS` list. (EEZ Studio
   exports the bitmap data as a new `.c` file but doesn't auto-register
   it in CMakeLists.)
6. `idf.py build flash`.

## Adding a custom font

1. Drop the source TTF / OTF into `assets/fonts/`.
2. In EEZ Studio, Fonts panel → Add. Point it at the file. Set the size,
   choose the codepoint range, save.
3. Reference the font in any style as `text_font: <font_name>`.
4. Save + Build.
5. Add the generated file to the build:
   `"ui/ui_font_<font_name>.c"` in [main/CMakeLists.txt](../main/CMakeLists.txt).
6. `idf.py build flash`.

If you used a font size that's available as an LVGL built-in (any
Montserrat 8–48), reference it in UPPERCASE (`MONTSERRAT_14`) instead —
no font file needed, just enable `CONFIG_LV_FONT_MONTSERRAT_14=y` in
[sdkconfig.defaults](../sdkconfig.defaults).

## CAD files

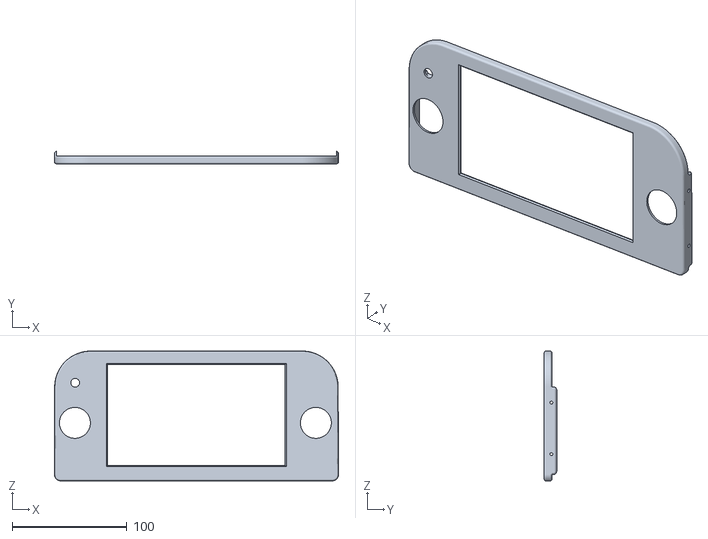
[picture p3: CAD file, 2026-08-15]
CAD/BodyWaveshareScreenCoverV1.stl
248.0 x 11.0 x 113.4

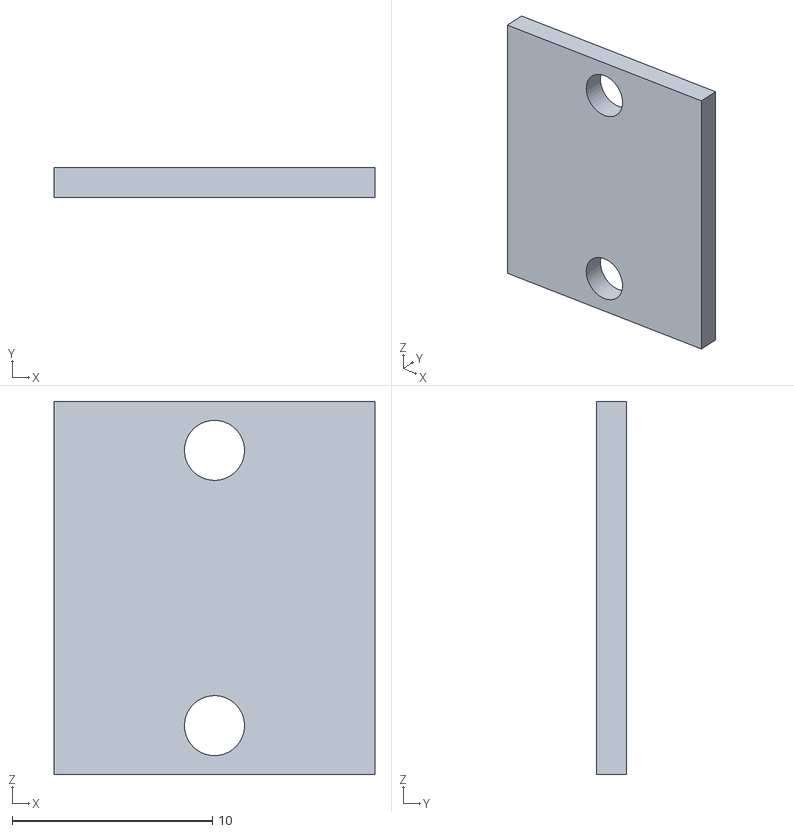
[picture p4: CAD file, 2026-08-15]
CAD/BodyPowerSwitchBackingPlateV1.stl
16.0 x 1.50 x 18.6

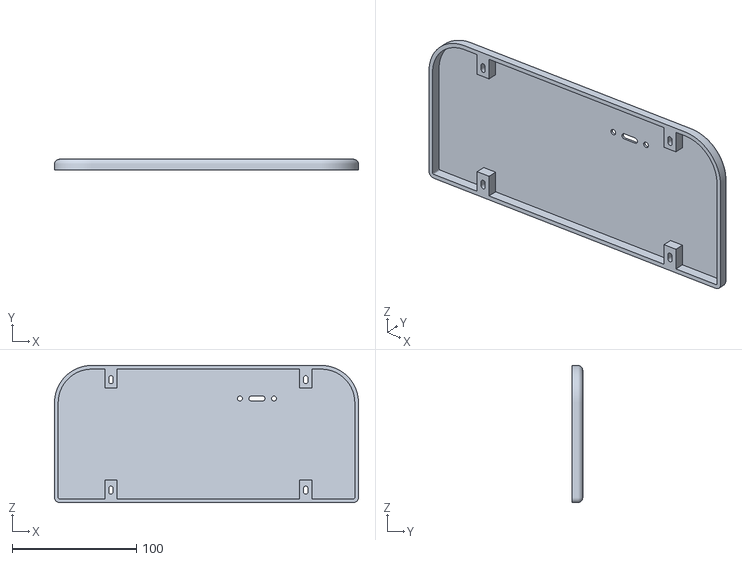
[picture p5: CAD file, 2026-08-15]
CAD/BodyWaveshareScreenBackplateV1.stl
245.0 x 8.50 x 110.5

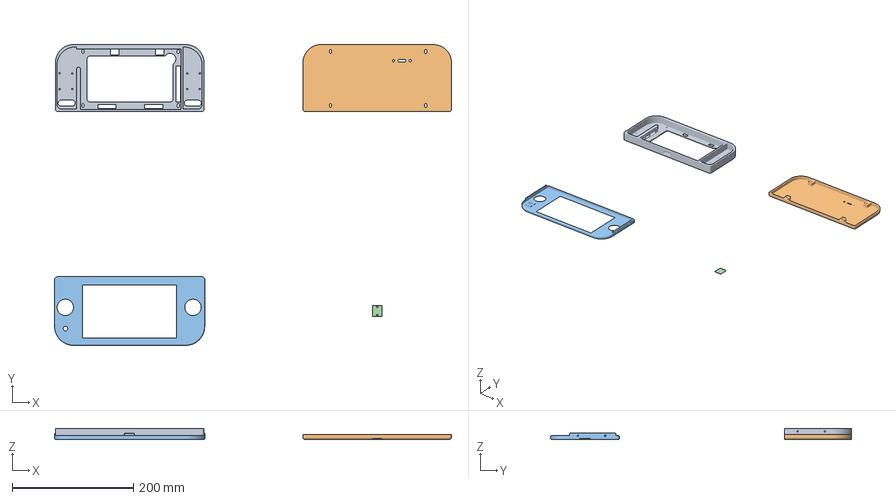
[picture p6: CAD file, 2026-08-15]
CAD/BodyWaveshareFluidNcPendant.3mf
654.5 x 496.0 x 18.2 mm
BodyWaveshareScreenBackplateV1.stl
BodyWaveshareScreenCoverV1.stl
BodyPowerSwitchBackingPlateV1.stl

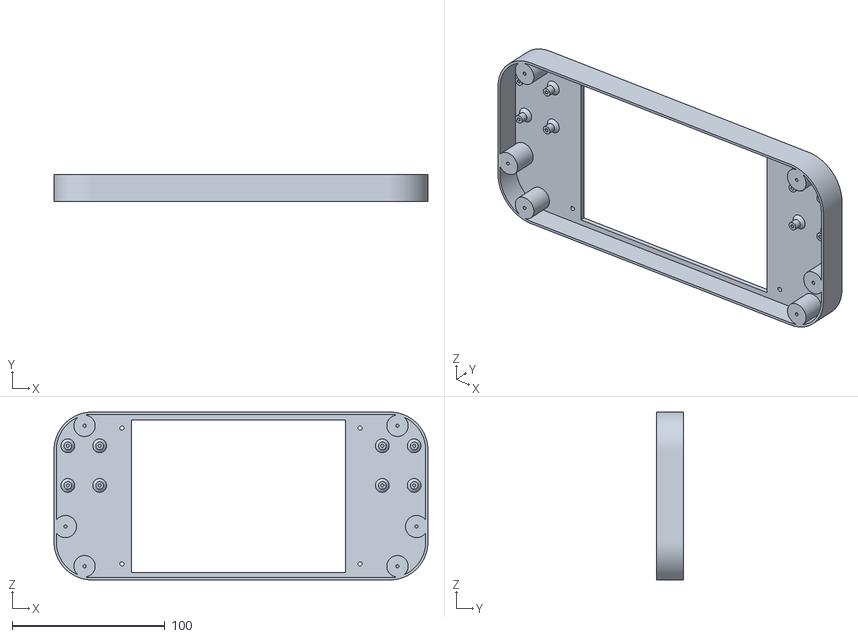
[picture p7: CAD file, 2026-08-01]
CAD/BodyWaveshareScreenBackingV2.stl
245.0 x 18.0 x 110.0

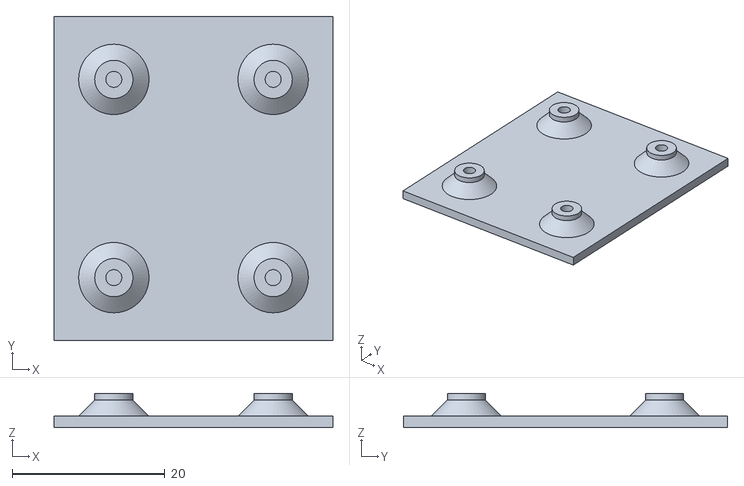
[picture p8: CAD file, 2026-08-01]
CAD/BodyJoystickTestV1.stl
36.5 x 42.4 x 4.50

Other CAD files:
CAD/TrailCurrentFluidNCPendantCaseV2.FCStd
CAD/BodyWaveshareScreenBackingV1.3mf
CAD/BodyWaveshareScreenBackingV1.stl

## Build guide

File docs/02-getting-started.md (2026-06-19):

# 02 — Getting started

This chapter walks through the very first time you power the pendant on.
It assumes the firmware is already flashed — if it isn't, do that first
([06 — Building and flashing](06-building-and-flashing.md)) and come back.

## What you need

- The Waveshare ESP32-P4 WiFi6 Touch LCD 7B board with firmware flashed.
- A USB-C cable to power it (any phone charger works — 5 V, 1 A is plenty).
- A WiFi network you can join. The pendant supports 2.4 GHz, WPA/WPA2/WPA3.
  5 GHz only networks won't work (the ESP32-C6 inside doesn't have a 5 GHz radio).
- Your FluidNC controller already configured and reachable on the same WiFi network
  (or wired to the pendant's UART pins — see *Wired connection* below).

## First boot

Plug in USB power. The screen will go through these stages:

1. **Black screen** for about 1 second while the ESP32 boots.
2. **Backlight comes on** and you see the LVGL UI initialise.
3. **WiFi Setup screen appears** — the pendant has scanned for networks and lists them.
4. (After WiFi connects) the pendant either skips straight to the **Dashboard**
   if you've used it before, or asks you to **Configure FluidNC Connection**.

That's it for a first-time happy-path boot. If the screen stays black for
more than 30 seconds, see [08 — Troubleshooting](08-troubleshooting.md).

## Connecting to WiFi

The WiFi Setup screen shows up to 8 nearby networks, sorted by signal strength.
Each row shows the network name (SSID), a signal-strength meter (0–3 bars),
and a padlock icon (locked = password required, unlocked = open).

```
┌────────────────────────────────────────────────┐
│  Connect to WiFi                               │
│  Pick a network to continue · or skip if you   │
│  prefer to wire the controller over serial     │
│                                                │
│  ┌──────────────────────────────────────────┐  │
│  │ ▮▮▮  HomeWiFi              🔒   →        │  │
│  │ ▮▮▯  Workshop              🔒   →        │  │
│  │ ▮▯▯  ShopGuest             🔓   →        │  │
│  │  ...                                     │  │
│  └──────────────────────────────────────────┘  │
│                                                │
│  [ Skip — Use Serial Only ]    [ ⟳ Rescan ]    │
└────────────────────────────────────────────────┘
```

### To join a network

1. Tap the row for the network you want.
2. If it's **open** (unlocked icon), the pendant connects immediately.
3. If it's **locked**, a password panel slides up with an on-screen keyboard.
   Type the password — you can tap the eye icon to show/hide it as you type.
4. Tap **Connect**. The pendant shows "Connecting to *YourNetwork*…" then
   either advances to the next screen or shows an error and goes back to
   the network list.

### Common errors

- **"Incorrect password."** — Re-tap the network and try again. The
  pendant doesn't save bad passwords, so you can keep trying.
- **"Network not in range."** — The signal dropped between scanning and
  connecting. Tap Rescan and try again.
- **"Timed out joining."** — The router took too long to respond. Rescan,
  or move closer.

The pendant **saves the credentials** to flash on the first successful
connect, so future boots auto-reconnect silently — you'll only see the WiFi
Setup screen again if you tap **Forget** in Settings → Connection, or if
the saved network disappears.

### Skipping WiFi

The **Skip — Use Serial Only** button is for setups where you'll wire the
pendant directly to the FluidNC controller's UART pins (see *Wired
connection* below). After tapping skip, the pendant goes straight to the
Dashboard and the FluidNC backend is set to UART.

## Connecting to FluidNC (the first time)

After WiFi joins, the pendant checks whether you've configured a FluidNC
controller before. If not, it shows the **FluidConnect** screen:

```
┌────────────────────────────────────────────────────────────┐
│  ●  TrailCurrent                              ●  WiFi 🟢   │
│                                                            │
│  Connect your FluidNC controller                           │
│  Pick a transport and tell us where to find it             │
│                                                            │
│  ┌────────── Transport ──────────┐                         │
│  │ ▣  ⟨⟩  WebSocket    Wireless  │  ← (pick one)           │
│  │ ▢  ⥨  UART          Wired     │                         │
│  │ ▢  ▦  Telnet        Wireless  │                         │
│  └───────────────────────────────┘                         │
│  ┌────────── Host & Port ────────────────────┐             │
│  │ [ 192.168.1.42      ] [ 81 ] [ CONNECT ]  │             │
│  └───────────────────────────────────────────┘             │
│  ●  Disconnected                       [ Back to WiFi ]    │
└────────────────────────────────────────────────────────────┘
```

### Wireless connection (WebSocket — recommended for most setups)

1. Tap the **WebSocket** card. It'll show a green checkmark.
2. Tap the host field. A keyboard slides up.
3. Type your controller's address. This can be:
   - An **IP address** (`192.168.1.42`) — look it up on your router's admin page,
     or in FluidNC's web UI under the System tab.
   - A **hostname** (`fluidnc.local`) — works on most home networks that support
     mDNS / Bonjour.
4. Tap the port field. The keyboard switches to numeric mode.
5. Type the port. Defaults:
   - **`81`** for FluidNC 3.x (the current 2026 release line)
   - **`80`** for FluidNC 4.x and later
   - If unsure, try 81 first.
6. Tap **CONNECT**. The status dot at the bottom turns green when the
   pendant successfully reaches the controller.
7. The pendant transitions to the Dashboard with live machine readouts.

### Wired connection (UART)

Use this if you want a wired link with no WiFi involvement — slightly more
reliable for permanent installs but requires a physical connection.

1. Wire the pendant's UART pins to the FluidNC controller's UART:
   - Pendant GPIO 5 (TX) → Controller RX
   - Pendant GPIO 4 (RX) → Controller TX
   - Pendant GND → Controller GND
2. On the FluidConnect screen, tap the **UART** card.
3. Tap **CONNECT** (host/port fields are ignored for UART).

The default baud rate is 115200 8N1; match this in your FluidNC YAML config.

## After you're connected

You land on the Dashboard. From here you can:

- Tap any axis chip (X / Y / Z) to **zero** that axis in the current work coordinate system.
- Drag the override sliders (Feed, Rapid, Spindle) to scale FluidNC's motion in real time.
- Tap any of the eight tabs in the bottom dock to switch screens.
- Tap the red **E-STOP** in the top-right to soft-reset the controller (panic button).

What every screen actually does is documented in [03 — Screen tour](03-screen-tour.md).

## Subsequent boots

After the first successful setup:
- WiFi auto-connects from saved credentials in about 4 seconds.
- The FluidNC connection is re-established to your saved host/port.
- The pendant lands directly on the **Dashboard** — no setup screens shown.

If the FluidNC controller is offline when the pendant boots, the status
pill in the top bar shows **OFFLINE** and the pendant retries automatically
every few seconds. As soon as the controller comes online the pill flips
to **IDLE** and live data starts flowing.

## Changing the connection later

- **Different WiFi network:** Settings → Connection → **Change Network**.
  This takes you back to the WiFi setup screen so you can pick a different SSID.
- **Different FluidNC controller:** Settings → Machine → **Configure FluidNC Connection**.
  Same FluidConnect screen as first boot, but reachable without re-doing WiFi.
- **Forget WiFi entirely:** Settings → Connection → **Forget**. The pendant
  drops the saved credentials and shows the WiFi setup screen on the next boot.

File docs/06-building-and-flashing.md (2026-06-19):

# 06 — Building and flashing

How to compile the firmware and get it onto the pendant. If you only
want to *use* the pendant, you can skip this chapter — flashed firmware
should be self-contained.

## Prerequisites

| Tool | Version | Purpose |
|---|---|---|
| [ESP-IDF](https://docs.espressif.com/projects/esp-idf/en/latest/esp32p4/get-started/) | 5.5.2+ | Compiler, build system, flash tool |
| [EEZ Studio](https://www.envox.eu/studio/) | latest | UI designer (only needed if you'll edit screens) |
| Linux / macOS / Windows | any recent | Host machine for the build |
| USB-C cable | any data-capable cable | Power + flashing |

Install ESP-IDF following the [official guide](https://docs.espressif.com/projects/esp-idf/en/latest/esp32p4/get-started/index.html) for your OS. The pendant targets the **ESP32-P4** chip; make sure your IDF install includes support for it.

## One-time setup

```bash
# Clone or copy the project
cd /path/to/TrailCurrentFluidCNCPendant

# Source the ESP-IDF environment (do this in every new terminal)
. ~/esp/v5.5.2/esp-idf/export.sh

# Tell IDF the target chip (only required once per checkout)
idf.py set-target esp32p4

# Pull managed component dependencies (esp_websocket_client etc.)
idf.py reconfigure
```

## Build

```bash
idf.py build
```

A clean build takes about 30 seconds on a modern laptop, 90 seconds on a
slow one. Subsequent rebuilds are incremental.

Output goes to `build/trailcurrent_fluidcnc_pendant.bin` (about 1.9 MB).

## Flash

Plug the pendant into your computer via USB-C. The board enumerates as
`/dev/ttyACM0` on Linux, `/dev/cu.usbmodem*` on macOS, `COM*` on Windows.

```bash
idf.py -p /dev/ttyACM0 flash
```

Flashing takes about 20 seconds. The board auto-resets after flashing
and starts running the new firmware.

## Monitor the serial console

To watch boot messages and log output:

```bash
idf.py -p /dev/ttyACM0 monitor
```

Exit with `Ctrl-]`. To flash and monitor in one go:

```bash
idf.py -p /dev/ttyACM0 flash monitor
```

## Configuring the build (menuconfig)

The most common reason to use `menuconfig` is to switch between the
real FluidNC backend and the bench-testing mock:

```bash
idf.py menuconfig
# → TrailCurrent FluidNC → [ ] Use mock backend (no real controller)
# Tap space to toggle, "S" to save, "Q" to quit
idf.py build flash
```

Other useful menus:

- **Component config → ESP-Hosted** — WiFi co-processor settings (don't
  change unless you know what you're doing; defaults work).
- **Component config → LVGL → Font** — additional Montserrat font sizes
  if you reference one in EEZ Studio that isn't currently enabled.

> ⚠️ **Don't edit `sdkconfig` directly.** It's regenerated on every
> build. Put changes in [`sdkconfig.defaults`](../sdkconfig.defaults).

## When something doesn't compile

| Error | Cause | Fix |
|---|---|---|
| `undefined reference to objects.<name>` | EEZ Studio Build hasn't run since the `.eez-project` changed | Open EEZ Studio, press Ctrl+B, retry `idf.py build` |
| `undefined reference to action_<Name>` | New action declared in EEZ Studio but no C handler in [actions.c](../main/actions.c) | Add `void action_<Name>(lv_event_t *e) { … }` to actions.c |
| `'ui_font_<name>' undeclared` | Custom font added but its `.c` file isn't in main/CMakeLists.txt | Add `"ui/ui_font_<name>.c"` to the `SRCS` list |
| `undefined reference to img_<name>` | New bitmap added but its `.c` file isn't in CMakeLists | Add `"ui/ui_image_<name>.c"` to `SRCS` |

More in [08 — Troubleshooting](08-troubleshooting.md).

## Releasing a binary

If you want a flashable image to share with someone who doesn't have
ESP-IDF installed, after a successful build you can produce a single
combined binary:

```bash
cd build
esptool.py --chip esp32p4 merge_bin \
    -o trailcurrent_pendant_full.bin \
    --flash_mode dio --flash_size 32MB --flash_freq 80m \
    0x2000 bootloader/bootloader.bin \
    0x8000 partition_table/partition-table.bin \
    0x10000 trailcurrent_fluidcnc_pendant.bin
```

The resulting `trailcurrent_pendant_full.bin` can be flashed with any
ESP-IDF or esptool installation:

```bash
esptool.py --chip esp32p4 -p /dev/ttyACM0 write_flash 0x0 trailcurrent_pendant_full.bin
```

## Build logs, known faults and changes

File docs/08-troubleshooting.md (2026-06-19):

# 08 — Troubleshooting

Things that go wrong, and what to do about them.

## Boot / display

### Screen stays black after powering on

- **Wait 30 seconds.** First boot after a fresh flash takes about 12 s
  before the backlight comes on; nothing's wrong if the screen is still
  off at 10 s.
- **Check the USB cable.** Some USB cables only carry power, not data.
  Use a known-good one.
- **Try a different USB port or power source.** The pendant draws up to
  500 mA in inrush; some PC USB ports can't deliver that cleanly.
- **Look at the serial console.** Connect `idf.py monitor` and watch for
  errors during boot. Typical successful boot starts with
  `ESP-ROM:esp32p4-eco2-…` and ends with `fluidcnc-pendant: boot complete`.

### Screen is on but shows a placeholder ("Run EEZ Studio Build…")

The firmware was built before the EEZ Studio export ran, so it has no
UI compiled in. Open the .eez-project in EEZ Studio, press **Ctrl+B**,
then `idf.py build flash`.

## WiFi

### "Incorrect password"

You typed the wrong password. Pick the network again and try.

### "Network not in range"

The signal dropped or the SSID isn't visible. Tap **Rescan** and retry.
If your network is 5 GHz-only, the pendant can't see it — you need a
2.4 GHz band on the same router.

### WiFi auto-reconnect doesn't happen on boot

Saved credentials may have failed validation. Go to Settings →
Connection → **Forget** and re-do the WiFi setup from scratch.

### WiFi connected but FluidNC says OFFLINE

The pendant has joined WiFi but can't reach the controller. Check:

- Is the controller powered on and on the same WiFi network?
- Is the host / IP correct? Open FluidNC's web UI in a browser from your
  laptop to confirm reachability.
- Is the port correct? FluidNC 3.x defaults to 81; FluidNC 4.x to 80.

## FluidNC connection

### Status pill always shows OFFLINE

The transport opened but no status reports are coming back. Possible
causes:

- **Wrong host/port.** Re-enter in Settings → Machine → Configure FluidNC.
- **FluidNC firewalled or disabled WebSockets.** Check the controller's
  YAML config — `websocket: enable: true` should be set.
- **UART wiring wrong.** Verify TX/RX swap (pendant TX → controller RX,
  pendant RX → controller TX). Common mistake.
- **UART baud mismatch.** The pendant uses 115200 8N1; the controller
  must match.

### Buttons don't do anything

Tap a button and nothing happens? Possibilities:

- **Controller in alarm.** Tap the alarm reset (the **R** on the red
  alarm ribbon, or the alarm-state pill) to send `$X`.
- **Controller running a job.** Some commands queue, some are ignored
  during a run. Stop the job first if needed.
- **Link is down.** Check the status pill — if it's red OFFLINE the
  command isn't going anywhere.

### Alarm shows "ALARM N" with no explanation

The pendant currently surfaces the alarm code but doesn't decode it.
Reference: [grbl alarm codes](https://github.com/gnea/grbl/wiki/Grbl-v1.1-Interface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).

Common ones:
- **Alarm 1** — Hard limit triggered.
- **Alarm 2** — Soft limit alarm (motion target outside soft limits).
- **Alarm 9** — Reset while in motion (the soft reset from E-STOP).
- **Alarm 10** — Homing required.

## Build / flash

### `idf.py: command not found`

You haven't sourced the ESP-IDF environment in this terminal. Run:

```bash
. ~/esp/v5.5.2/esp-idf/export.sh
```

(Adjust path to wherever you installed IDF.)

### `Permission denied: '/dev/ttyACM0'`

On Linux, your user isn't in the `dialout` group:

```bash
sudo usermod -a -G dialout $USER
# Then log out + back in for the group change to take effect
```

### `undefined reference to objects.<widget>`

EEZ Studio Build hasn't run since the .eez-project changed. Open the
project in EEZ Studio, press **Ctrl+B**, retry `idf.py build`.

### `undefined reference to action_<Name>`

EEZ Studio knows about an action that has no C implementation. Either:

- Add the implementation in [main/actions.c](../main/actions.c), or
- Remove the action from the .eez-project if it's not actually needed.

### `'ui_font_<name>' undeclared`

The font is referenced from `styles.c` but the corresponding `.c` file
isn't in the build. Add it to [main/CMakeLists.txt](../main/CMakeLists.txt)
`SRCS`:

```cmake
"ui/ui_font_<name>.c"
```

### `undefined reference to img_<name>` at link time

Same problem as missing font, for bitmaps. Add `"ui/ui_image_<name>.c"`
to [main/CMakeLists.txt](../main/CMakeLists.txt) `SRCS`.

### Empty squares `[]` appear in label text

The character you're trying to render isn't in the font's subset. Either:

- Use a different character (often the case for em-dash `—` vs hyphen
  `-`), or
- Add the codepoint to the font's `lvglRanges` in EEZ Studio
  (see [07 — Customizing](07-customizing.md), "Adding a Font Awesome icon").

## UI / interaction

### Touch is unresponsive in one area of the screen

The touch controller (GT911) maps to a fixed 1024×600 grid. If you see
dead zones, it's probably a hardware issue with the panel ribbon
connector — re-seat it.

### A label is cut off / overflows its container

EEZ Studio doesn't auto-size labels to fit text. Two fixes:
- Make the label widget wider, OR
- Use a smaller font in its style.

Both done in EEZ Studio + Build + flash.

### The keyboard on PageFluidConnect won't go away

Tap the **Connect** button (it dismisses the keyboard automatically), or
press Enter on the keyboard. If those don't work, navigate away via the
Back button.

## Settings persist across reboots in unexpected ways

The pendant stores in NVS (flash):

- WiFi SSID + password
- FluidNC host, port, transport
- Units (mm/in)
- Soft / hard limits switches
- Home on boot switch
- Screen brightness
- Screen timeout (minutes)
- Default jog feed (mm/min)
- Theme (light/dark)

To wipe everything and start fresh:

```bash
idf.py -p /dev/ttyACM0 erase-flash
idf.py -p /dev/ttyACM0 flash
```

This wipes ALL of flash — code AND NVS — so the next boot is a true
factory-fresh experience.

## Performance

### UI feels sluggish during a long g-code run

The status poller runs at 250 ms (4 Hz). On a complex job you may see
the pendant updating one beat behind reality. This is a deliberate
trade-off — polling faster would consume more bandwidth and CPU. If
you need higher rates, edit `POLL_PERIOD_MS` near the top of
[components/fluidnc/src/fluidnc.c](../components/fluidnc/src/fluidnc.c).

### The screen looks dim

Settings → Display → Brightness. Saved to flash on each change.

## Getting more help

If you hit something that isn't in this list, the serial console
(`idf.py monitor`) is your best friend — most issues show up as
`E (…)` (error) or `W (…)` (warning) log lines with a tag indicating
which subsystem is unhappy.

The project's tag list (handy for filtering):

- `fluidcnc-pendant` — top-level init in `main.c`
- `app_state` — state-machine transitions
- `actions` — UI button handlers
- `fluidnc` — protocol dispatcher (real backend)
- `fluidnc_ws` — WebSocket transport
- `fluidnc_uart` — UART transport
- `wifi_setup` — WiFi scan + connect
- `pendant_cfg` — NVS load/save

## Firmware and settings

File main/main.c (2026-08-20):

#include "freertos/FreeRTOS.h"
#include "freertos/task.h"
#include "nvs_flash.h"
#include "nvs.h"
#include "esp_log.h"
#include "esp_err.h"
#include "esp_heap_caps.h"
#include "esp_event.h"
#include "esp_netif.h"
#include "lvgl.h"
#include "bsp/display.h"
#include "bsp/esp-bsp.h"

#include "app_state.h"
#include "pendant_config.h"
#include "thumbstick_monitor.h"
#include "battery_monitor.h"

#if __has_include("ui/ui.h")
#  include "ui/ui.h"
#  include "ui/vars.h"
#  include "ui/screens.h"
#  define HAVE_UI 1
#else
#  define HAVE_UI 0
#endif

static const char *TAG = "fluidcnc-pendant";

#define USER_SETTINGS_NVS_NAMESPACE "user_settings"

#if HAVE_UI
/* Restore brightness / timeout / jog-feed from NVS after ui_init() exposes the
 * value labels. Falls back to the defaults baked into vars.c when an entry is
 * missing — the first boot after flashing always uses the defaults. */
static void restore_user_settings_from_nvs(void)
{
    nvs_handle_t nvs;
    if (nvs_open(USER_SETTINGS_NVS_NAMESPACE, NVS_READONLY, &nvs) != ESP_OK) {
        ESP_LOGI(TAG, "user_settings NVS namespace not present — using defaults");
        bsp_display_lock(0);
        bsp_display_brightness_set((int)get_var_screen_brightness());
        bsp_display_unlock();
        return;
    }

    uint8_t theme = 0;
    if (nvs_get_u8(nvs, "theme", &theme) == ESP_OK) {
        if (theme > 1) theme = 1;
        set_var_selected_theme(theme);
        ESP_LOGI(TAG, "restored theme=%d", (int)theme);
    } else {
        set_var_selected_theme(get_var_selected_theme());
    }

    uint8_t brightness = 0;
    if (nvs_get_u8(nvs, "brightness", &brightness) == ESP_OK) {
        if (brightness < 10) brightness = 10;   /* keep screen actually visible */
        set_var_screen_brightness(brightness);
        bsp_display_brightness_set(brightness);
        ESP_LOGI(TAG, "restored brightness=%d", (int)brightness);
    } else {
        bsp_display_brightness_set((int)get_var_screen_brightness());
    }

    int8_t timeout = 0;
    if (nvs_get_i8(nvs, "timeout", &timeout) == ESP_OK) {
        if (timeout < 0)  timeout = 0;
        if (timeout > 60) timeout = 60;
        set_var_screen_timeout_value(timeout);
        ESP_LOGI(TAG, "restored timeout=%d min", (int)timeout);
    } else {
        /* Force the default into the value label so it isn't stuck at "5". */
        set_var_screen_timeout_value(get_var_screen_timeout_value());
    }

    int16_t jog_feed = 0;
    if (nvs_get_i16(nvs, "jog_feed", &jog_feed) == ESP_OK) {
        if (jog_feed < 60)   jog_feed = 60;
        if (jog_feed > 6000) jog_feed = 6000;
        set_var_default_jog_feed(jog_feed);
        ESP_LOGI(TAG, "restored jog_feed=%d mm/min", (int)jog_feed);
    } else {
        set_var_default_jog_feed(get_var_default_jog_feed());
    }

    int16_t stick_feed = 0;
    if (nvs_get_i16(nvs, "stick_feed", &stick_feed) == ESP_OK) {
        if (stick_feed < 60)   stick_feed = 60;
        if (stick_feed > 6000) stick_feed = 6000;
        set_var_stick_jog_feed(stick_feed);
        ESP_LOGI(TAG, "restored stick_feed=%d mm/min", (int)stick_feed);
    } else {
        /* First boot with this setting. Seed it from what the stick's
         * effective cap USED to be — min(default_jog_feed, 1500) — so the
         * stick feel doesn't change on already-deployed pendants until the
         * user moves the new slider. */
        int32_t seed = get_var_default_jog_feed();
        if (seed > 1500) seed = 1500;
        if (seed < 60)   seed = 60;
        set_var_stick_jog_feed(seed);
        ESP_LOGI(TAG, "stick_feed not set — seeded %d mm/min from legacy cap",
                 (int)seed);
    }

    /* Probe parameters — written by action_probe_edit_done as strings so
     * the user's typed value (e.g. "19.05") survives reboot. If the key
     * isn't present yet the vars.c defaults apply. */
    char buf[16];
    size_t len;
    len = sizeof(buf);
    if (nvs_get_str(nvs, "p_plate", buf, &len) == ESP_OK) {
        set_var_probe_plate_thickness(buf);
        ESP_LOGI(TAG, "restored probe plate=%s", buf);
    }
    len = sizeof(buf);
    if (nvs_get_str(nvs, "p_feed", buf, &len) == ESP_OK) {
        set_var_probe_feed(buf);
        ESP_LOGI(TAG, "restored probe feed=%s", buf);
    }
    len = sizeof(buf);
    if (nvs_get_str(nvs, "p_travel", buf, &len) == ESP_OK) {
        set_var_probe_max_travel(buf);
        ESP_LOGI(TAG, "restored probe travel=%s", buf);
    }
    /* Corner-probe geometry (row 2 tiles). */
    len = sizeof(buf);
    if (nvs_get_str(nvs, "p_xytrav", buf, &len) == ESP_OK) {
        set_var_probe_xy_travel(buf);
    }
    len = sizeof(buf);
    if (nvs_get_str(nvs, "p_depth", buf, &len) == ESP_OK) {
        set_var_probe_edge_depth(buf);
    }
    len = sizeof(buf);
    if (nvs_get_str(nvs, "p_tooldia", buf, &len) == ESP_OK) {
        set_var_probe_tool_dia(buf);
    }
    len = sizeof(buf);
    if (nvs_get_str(nvs, "p_edgethk", buf, &len) == ESP_OK) {
        set_var_probe_edge_thick(buf);
    }

    nvs_close(nvs);
}

/* Inactivity blanking — when no touch has fired for `screen_timeout_value`
 * minutes, dim the backlight to the minimum-visible floor and overlay a
 * full-screen invisible touch absorber. The next touch restores brightness.
 *
 * Floor is BLANK_BRIGHTNESS_FLOOR — 10/255 keeps the panel safely visible
 * (so the user can tell the device is alive and find where to touch),
 * doesn't burn power, and avoids the brownout-on-wake we saw at 0. The
 * EK79007 panel's LED driver spikes inrush current re-enabling from full
 * off; keeping the LED warm at 10 sidesteps that entirely. */
#define BLANK_BRIGHTNESS_FLOOR 10

static lv_obj_t *s_wake_overlay = NULL;
static int32_t   s_brightness_before_blank = 180;

static void wake_touch_cb(lv_event_t *e)
{
    (void)e;
    /* Defensive floor — if the saved brightness is below visible (user
     * had dragged the slider to near-zero before the screen blanked),
     * restore to the same floor we use for blanking. Otherwise the screen
     * stays apparently off after wake and the user can't recover. */
    int restore = (int)s_brightness_before_blank;
    if (restore < BLANK_BRIGHTNESS_FLOOR) restore = BLANK_BRIGHTNESS_FLOOR;
    bsp_display_brightness_set(restore);
    if (s_wake_overlay) {
        lv_obj_del(s_wake_overlay);
        s_wake_overlay = NULL;
    }
    ESP_LOGI(TAG, "screen wake — restored brightness %d", restore);
}

static void inactivity_blank_task(void *arg)
{
    (void)arg;
    while (1) {
        vTaskDelay(pdMS_TO_TICKS(1000));
        int32_t timeout_min = get_var_screen_timeout_value();
        if (timeout_min <= 0) continue;  /* 0 = disabled */

        bsp_display_lock(0);
        uint32_t idle_ms = lv_disp_get_inactive_time(NULL);
        bool already_blanked = (s_wake_overlay != NULL);
        if (!already_blanked && idle_ms >= (uint32_t)timeout_min * 60u * 1000u) {
            s_brightness_before_blank = get_var_screen_brightness();
            bsp_display_brightness_set(BLANK_BRIGHTNESS_FLOOR);
            s_wake_overlay = lv_obj_create(lv_layer_top());
            lv_obj_remove_style_all(s_wake_overlay);
            lv_obj_set_size(s_wake_overlay, LV_PCT(100), LV_PCT(100));
            lv_obj_add_flag(s_wake_overlay, LV_OBJ_FLAG_CLICKABLE);
            lv_obj_clear_flag(s_wake_overlay, LV_OBJ_FLAG_SCROLLABLE);
            lv_obj_add_event_cb(s_wake_overlay, wake_touch_cb,
                                LV_EVENT_CLICKED, NULL);
            ESP_LOGI(TAG, "screen blanked after %d min inactivity",
                     (int)timeout_min);
        }
        bsp_display_unlock();
    }
}
#endif /* HAVE_UI */

void app_main(void)
{
    ESP_LOGI(TAG, "TrailCurrent FluidCNC Pendant booting");

    /* --- NVS (must come before WiFi or persistent config). --- */
    esp_err_t ret = nvs_flash_init();
    if (ret == ESP_ERR_NVS_NO_FREE_PAGES || ret == ESP_ERR_NVS_NEW_VERSION_FOUND) {
        ESP_ERROR_CHECK(nvs_flash_erase());
        ret = nvs_flash_init();
    }
    ESP_ERROR_CHECK(ret);

    /* --- Default event loop (WiFi needs it, the BSP doesn't create one). --- */
    ESP_ERROR_CHECK(esp_event_loop_create_default());

    /* --- Persistent pendant config from NVS. --- */
    ESP_ERROR_CHECK(pendant_config_init());

    /* --- Display + LVGL via the Waveshare ESP32-P4 BSP. --- */
    bsp_display_cfg_t cfg = {
        .lvgl_port_cfg = {
            .task_priority      = 5,
            .task_stack         = 7168,
            .task_affinity      = 1,                 /* Core 1 — keep core 0 free for app/WiFi */
            .task_max_sleep_ms  = 500,
            .task_stack_caps    = MALLOC_CAP_INTERNAL | MALLOC_CAP_DEFAULT,
            .timer_period_ms    = 5,
        },
        .buffer_size   = BSP_LCD_H_RES * 100,        /* Larger draw buffer = fewer flushes */
        .double_buffer = 1,
        .flags = {
            .buff_dma    = false,
            .buff_spiram = true,                     /* Use PSRAM for draw buffers */
            .sw_rotate   = true,                     /* Match Fireside — required for 180° rotation */
        },
    };
    lv_display_t *disp = bsp_display_start_with_config(&cfg);
    bsp_display_backlight_on();
    if (disp == NULL) {
        ESP_LOGE(TAG, "Display init failed");
        return;
    }
    /* Match Fireside: panel mounted upside-down in the case, rotate 180°. */
    bsp_display_rotate(disp, LV_DISPLAY_ROTATION_180);

    /* --- Initialize the EEZ Studio-generated UI tree. --- */
#if HAVE_UI
    bsp_display_lock(0);
    ui_init();
    bsp_display_unlock();
    ESP_LOGI(TAG, "UI initialized");

    /* Restore persisted Display / Motion preferences and apply brightness
     * to the panel. Must come AFTER ui_init() because set_var_*() pokes the
     * value labels (and slider knobs) created during init. */
    restore_user_settings_from_nvs();

    /* Push "not yet connected" defaults into every widget — overwrites the
     * demo text the .eez-project ships with (bracket_v3.nc, 12000 RPM, etc.)
     * so the user never sees stale mock data before the dispatcher delivers
     * real status. Must come AFTER ui_init() too. */
    app_state_paint_initial_state();

    xTaskCreatePinnedToCore(inactivity_blank_task, "blank", 3072,
                            NULL, 4, NULL, 0);
#else
    /* UI hasn't been exported from EEZ Studio yet — show a placeholder so the
     * device at least boots cleanly. Open the .eez-project and Build (Ctrl+B)
     * to populate main/ui/. */
    bsp_display_lock(0);
    lv_obj_t *label = lv_label_create(lv_scr_act());
    lv_label_set_text(label,
        "FluidCNC Pendant\n"
        "Run EEZ Studio Build to populate the UI.");
    lv_obj_align(label, LV_ALIGN_CENTER, 0, 0);
    bsp_display_unlock();
    ESP_LOGW(TAG, "ui.h not found — EEZ Studio export needed");
#endif

    /* --- Diagnostic: thumbstick wiring monitor (logs ADC + digital state). --- */
    thumbstick_monitor_start();

    /* --- Battery monitor: on-board voltage divider on GPIO20 -> SOC + charging. --- */
    battery_monitor_start();

    /* --- Boot the state machine; this advances to WIFI_SETUP or WIFI_CONNECTING
     *     depending on whether NVS already has credentials. --- */
    ESP_ERROR_CHECK(app_state_init());

    /* --- LVGL tick driver runs in its own BSP task — nothing else for app_main. --- */
    ESP_LOGI(TAG, "boot complete");
}

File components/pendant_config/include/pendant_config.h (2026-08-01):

#pragma once

/*
 * Pendant persistent configuration (NVS-backed).
 *
 * Single source of truth for all user-entered settings the pendant remembers
 * across reboots: WiFi credentials, FluidNC transport, units preference,
 * limits toggles, etc. No SD-card / external-file path — the touchscreen UI is
 * the only configuration surface.
 *
 * NVS namespace: "pendant".
 */

#include <stdbool.h>
#include <stddef.h>
#include <stdint.h>
#include "esp_err.h"

#ifdef __cplusplus
extern "C" {
#endif

#define PENDANT_CFG_SSID_MAX    33      /* 32 + NUL */
#define PENDANT_CFG_PASS_MAX    65      /* 64 + NUL */
#define PENDANT_CFG_HOST_MAX    65      /* hostname/IP + NUL */

typedef enum {
    PENDANT_TRANSPORT_UART      = 0,
    /* RETIRED 2026-08: WebSocket was dropped as a transport (FluidNC 4.x's
     * WS server reset connections under load; telnet proved stable). The
     * enum value is kept so a stored NVS byte of 1 on already-deployed
     * units still parses — pendant_config_init() coerces it to TELNET. */
    PENDANT_TRANSPORT_WEBSOCKET = 1,
    PENDANT_TRANSPORT_TELNET    = 2,
} pendant_transport_t;

typedef enum {
    PENDANT_UNITS_MM   = 0,
    PENDANT_UNITS_INCH = 1,
} pendant_units_t;

typedef struct {
    /* WiFi */
    char     wifi_ssid[PENDANT_CFG_SSID_MAX];
    char     wifi_pass[PENDANT_CFG_PASS_MAX];

    /* FluidNC connection
     *   transport      — UART (wired) / WebSocket (wireless) / Telnet (rare)
     *   host           — hostname/IP for WS/Telnet; ignored for UART
     *   port           — WebSocket: 81 (FluidNC 3.x, default) or 80 (4.x);
     *                    Telnet: 23. Ignored for UART.
     */
    pendant_transport_t fluid_transport;
    char     fluid_host[PENDANT_CFG_HOST_MAX];
    uint16_t fluid_port;

    /* User preferences */
    pendant_units_t units;
    bool     soft_limits;
    bool     hard_limits;
    bool     home_on_boot;
} pendant_config_t;

/* Initialize NVS namespace and load config into the global cache.
 * If no config has been saved yet, fills the cache with defaults
 * (empty creds, transport=UART, units=mm, soft+hard limits on, home_on_boot off).
 */
esp_err_t pendant_config_init(void);

/* Pointer to the in-memory cached config. Read-only access is fine without a
 * lock; mutating fields directly is NOT safe — use the setters below so the
 * NVS write happens atomically.
 */
const pendant_config_t *pendant_config_get(void);

/* True when WiFi SSID is non-empty (i.e. user has saved credentials before). */
bool pendant_config_has_wifi(void);

/* True when FluidNC host or transport has been configured (UART transport
 * needs no host, so transport != default is enough). */
bool pendant_config_has_fluid(void);

/* --- Setters: each writes the field to NVS and updates the cache. --- */
esp_err_t pendant_config_set_wifi(const char *ssid, const char *pass);
esp_err_t pendant_config_clear_wifi(void);

esp_err_t pendant_config_set_fluid_transport(pendant_transport_t t);
esp_err_t pendant_config_set_fluid_host(const char *host);
esp_err_t pendant_config_set_fluid_port(uint16_t port);

esp_err_t pendant_config_set_units(pendant_units_t u);
esp_err_t pendant_config_set_soft_limits(bool on);
esp_err_t pendant_config_set_hard_limits(bool on);
esp_err_t pendant_config_set_home_on_boot(bool on);

#ifdef __cplusplus
}
#endif

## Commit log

2026-06-14 Project started for YouTube EEZ Studio demo
    [partitions.csv]
2026-06-19 Testing functional possibilities
    [idf_component.yml]
2026-06-19 Adding physical joysticks for jogging and fixing some observed errors
    [actions.c, fluidnc.c, fluidnc_mock.c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]
2026-06-19 Fixed values not saving for probe settings, alarm ribbon shows alarm state, updates to watchdog to improve reliability
    [vars.c]
2026-06-19 Fixing bars not showing relative percentage on dashboard. Swapping the flood button for a soft reset button instead.
    [vars.c]
2026-06-19 Fixing button alignment. Updating so SD card screen points to FluidNC SD card not the pendant
    [fluidnc.c, fluidnc_mock.c]
2026-08-01 Lots of work put into making movements smooth and solving bugs. Also the case design is completely different now
    [BodyJoystickTestV1.stl, BodyWaveshareScreenBackingV1.3mf, BodyWaveshareScreenBackingV1.stl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]
2026-08-01 Z Probe bug fixed
    [actions.c, fluidnc.c, vars.c]
2026-08-01 X, Y, X probe values available and sequence is working
2026-08-01 Fixed values on settings screen
    [fluidnc.c, vars.c]
2026-08-01 Fixed files showing that aren't .nc files. Added loading icon so the user knows to wait. Soft limits shoudl be fixed
    [actions.c, fluidnc.c, fluidnc_mock.c]
2026-08-01 Removed clock toolbar was too cluttered and it didn't add any value
    [vars.c, vars.h]
2026-08-01 Add x 0 y 0 macro to the macros screen, cleanup of labels that can't be populated and a bug fix for the hold / resume on the job page.
    [actions.c, vars.c]
2026-08-01 Fix bug of missing icon for the files screen. Showing sd card info now
    [fluidnc.c]
2026-08-02 Switching keyboard to custom that way entering GCode is easier
2026-08-02 Adding OTA so we can update firmware without USB connection
    [partitions.csv]
2026-08-11 CAD Updates
    [TrailCurrentFluidNCPendantCaseV2.FCStd]
2026-08-15 Latest CAD changes
    [BodyPowerSwitchBackingPlateV1.stl, BodyWaveshareFluidNcPendant.3mf, BodyWaveshareScreenBackplateV1.stl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]
2026-08-29 Fixing static feed rate label and improving responsiveness of feed rate overrideI
    [actions.c, fluidnc.c, fluidnc_mock.c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]
2026-09-16 Fixed bug preventing files from loading correctly
    [actions.c]
2026-09-16 Upaded file list to be scrollable and removed fixed number of items left over from the mockup
    [actions.c, fluidnc.c, fluidnc_mock.c]
2026-09-17 Fixes to file loading in pendant
    [fluidnc.c, vars.c]
2026-09-27 Active screen now indicated in bottom nav. Sub folders now accessible on SD card files screen. Fixed bug with x0 y0 macro being slow to respond.
    [actions.c, fluidnc.c, fluidnc_mock.c]
2026-10-02 Pin esp_lvgl_port to 2.8.0 to fix build on IDF 5.5.2
    esp_lvgl_port arrives transitively via the Waveshare BSP as ^2 and dependencies.lock is untracked, so fresh clones resolved 2.9.0, which references on_frame_buf_complete in esp_lcd_dpi_panel_event_callbacks_t. IDF 5.5.2 still names that member on_refresh_done, so the build failed.
    Fixes #1
